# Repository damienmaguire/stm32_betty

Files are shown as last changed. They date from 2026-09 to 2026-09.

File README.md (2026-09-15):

# stm32_betty

Gen 2 Prius (NHW20) Battery ECU on a **ZombieVerter VCU V1.3**.

This software enables the use of 3 × BMW Gen 1 PHEV 16s modules (48s, 26 Ah) as the hybrid battery in a Gen 2 Toyota Prius car.

PHEV fuction via a Prius Plug-In OBC G9090-47040 in progress.
install1

Charger install in progress:
Charger_install

CAUTION : THIS FIRMWARE IS ALMOST ENTIRELY AI WRITTEN AND HAS NOT AS YET BEEN ROAD TESTED.

Provides various drive modes on the web interface.

## Buses

| Bus | Rate | Use |
|---|---|---|
| CAN1 | 500 k | Prius `0x03B` / `0x3C9` / `0x3CB` / `0x3CD` / `0x4D1` |
| CAN2 | 500 k | BMW CSC poll `0x080–0x085`, replies addrs 2/3/4 |
| GP_analog1 (PC2) | — | Prius Hall after 1k/1k on V1.3 |
| USART3 | 115200 | OpenInverter terminal + ESP web |

## Drive modes (ESP page, category Drive Mode)

| `mode` | What the HV ECU is told |
|---|---|
| 0 Hold | Default. Real 25–85 % mapped to a Prius 50–70 % report |
| 1 CD | Report `cdspoof` (~74 %) until `socreal` ≤ `cdfloor`, then Hold |
| 2 EV | Report `evspoof` (~60 %) and keep CCL ≥ 60 so the EV button is allowed |
| 3 Range | CDL = 0 — force the engine |
menu

## Build

```bash
sudo apt install gcc-arm-none-eabi
git clone --recurse-submodules https://github.com/damienmaguire/stm32_betty.git
cd stm32_betty
make
```

`make` runs `get-deps`: initialises the libopencm3 / libopeninv submodules (or clones them if you grabbed a zip) and builds `libopencm3` for STM32F1.

Flash like any Zombie. Linker origin is **0x08001000** (OpenInverter bootloader):

Or the ESP web updater / CubeProgrammer.

## Wiring (V1.3)

- Prius hybrid CAN → CAN1
- CSC loom (Yel/Brn + Yel/Red, 5 V + GND) → CAN2
- Hall yellow after 1k/1k → GP analog 1. Rest `ibpin` ≈ 1.21–1.25 V
- Board 12 V from IGCT (or parked 12 V). Sleep-override jumper fitted
- `CANEN` / `CANSBY` driven in firmware

## Status (2026-09-11)

Firmware v4. Pack in, IGCT Ready, no triangle.

GPL-3.0, same as OpenInverter / Zombie.

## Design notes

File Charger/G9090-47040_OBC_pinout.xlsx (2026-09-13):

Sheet: Notes
Betty — Toyota Prius Plug-In OBC G9090-47040 (ZVW35) pinout
Electric Vehicle Charger Assembly • connectors L120(A) / T10(B) / T11(C) • from OEM EWD snippet + ATI ZVW35 notes • 2026-09-13
What this unit is
Air-cooled Prius Plug-In onboard charger, part G9090-47040, 2012–2015 ZVW35. OEM rating is roughly 2 kW class on a 15 A EVSE.
How OEM drives it
Stock car has a Plug-in Charge Control ECU (PCC).Sends CHRQ + CHPW, reads CHST + VCHG.Zombie will fake those four wires.
HV path on Betty
DCHG is HV DC−, DCHB is HV DC+. Fuse DCHB, then land on the pack side of the Prius SMRs.
12 V
IGCT (A1, blue/L) with the VCU. Same rail that already boots the CSCs. CGND (A6 brown) is the charger signal ground — bond it to VCU ground.
EVSE / inlet
Right-hand block is the charge inlet: ACIH / ACIC (mains), GND, CPLT (J1772 control pilot), PISW (proximity / connector-present via the onboard resistor). CPG is pilot/PE ground.
Safety
Mains and HV on the same assembly. Isolate, fuse ACIH, fuse DCHG. No Prius frames on CAN2, no CSC frames on CAN1. This sheet is a wiring aid, not a live-work procedure.
Sheets: Pinout = every labelled net on the attached EWD. Diagram = the source drawing. Betty map = suggested landing on the Zombie / pack.

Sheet: Pinout
G9090-47040 • connections visible on the attached EWD
Connector family on the charger body: L120(A) T10(B) T11(C). Far-side IDs (E18, D27, At1, Ts1, T11) are as drawn. Colours are Toyota EWD codes.
Group | Signal | OBC pin | Far pin / ID | Colour | Class | Function | Betty / Zombie note
Control (PCC) | CHST | A2 | E18 CHST | G green | 12 V PWM out | Charge status from the OBC to the PCC ECU. Standby ≈ 25 ms B+ every 100 ms; ready ≈ 50 % duty; fault ≈ 78 % duty (overtemp / bad AC / internal). | Read on a Zombie GPIO or timer-in. Do not leave floating — PCC used it as the ‘charger is alive’ lamp.
Control (PCC) | CHPW | A3 | E19 CHPW | P pink | 12 V PWM in | Charge-power / current command from the PCC. 10 Hz PWM; on-time sets requested output. | Zombie must generate this. Start conservative (low duty).
Control (PCC) | CHRQ | A4 | E27 CHRQ | V purple | 12 V digital in | Charge request. High/low from the PCC: ‘please charge’. | Zombie GPIO out. Gate with umax / udc / EVSE present / Ready-not-in-Drive.
Control (PCC) | CGND | A6 | D27 CGND | BR brown | Signal GND | Charger control-signal ground. | Bond to VCU ground.
Control (PCC) | VCHG | A8 | D32 VCHG | W white | Analog out | Isolated analog of charger/pack voltage back to the PCC. OEM range quoted 1.72–6.0 V. | Useful cross-check vs CSC sumV.
Control (PCC) | VAC sense | A5 GVAC / A7 VAC1 | drawn as B and W pair | B black / W white | Analog / AC sense | GVAC and VAC1 sit on the same charger header as the PCC wires. Almost certainly AC-input voltage sense, not HV. | Leave unconnected until checked.
12 V power | IGCT | A1 | IGCT rail (blue) | L blue | 12 V in | Ignition / control power for the charger electronics. Same name as the Prius HV-ECU IGCT feed. | Tie to VCU IGCT. Board + CSCs + OBC cold-boot together. No permanent 12 V on the OBC until we know the no-IGCT draw.
HV DC out | DCHG | C2 | Ts1-1 | O-B orange/black, shielded | HV DC | HV DC− (negative). Shielded pair with DCHB. Lands on Ts1-1 in the drawing. | Fuse the positive (DCHB), then pack− side of the Prius SMRs. Confirmed: DCHG = DC−.
HV DC out | DCHB | C1 | Ts1-2 | O-W orange/white, shielded | HV DC | HV DC+ (positive). Shielded pair with DCHG. Lands on Ts1-2 in the drawing. | Fuse this leg, then pack+ side of the Prius SMRs. Confirmed: DCHB = DC+.
HV DC out | CHG | A12 | 4B-27 / 4A-42 | W-B white/black | 12 V / interlock (confirm) | Leaves the charger as W-B to a spliced junction (4B/4A). Not the orange HV pair. Likely charger +B, charge-relay coil, or an interlock — EWD snippet does not name the far ECU.
AC in | ACIH | B2 | T11-2 (inlet pin 1) | O-W orange/white, shielded | Mains Live | AC In Hot. Fused, CCID-protected live from the EVSE / inlet.
AC in | ACIC | B1 | T11-1 (inlet pin 2) | O-B orange/black, shielded | Mains Neutral | AC In Cold (neutral).
Inlet / J1772 | CPLT | inlet pin 4 → At1-1 | B23 CPLT | W white (then B at header) | Pilot | J1772 Control Pilot. EVSE PWM advertises available amps; vehicle pulls the pilot down to 6 V to say ‘ready’. | Zombie will handle
Inlet / J1772 | CPG | inlet / At1-3 | B10 CPG | W-B white/black | PE / pilot GND | Control-pilot / protective earth reference at the inlet header. | Chassis / PE.
Inlet / J1772 | PISW | inlet pin 5 → At1-2 | B12 PISW | B then R black/red | Proximity | Connector-present / proximity. Inlet pin 5 through the onboard PISW/CF resistor (green to earth) so the ECU sees a voltage, not a dead short. | Use as ‘plug is in’ before asserting CHRQ. <1 V typically means don’t charge; ~8 V means charge on the OEM PCC. Zombie will handle.
Inlet / J1772 | PISW resistor | inlet CF block | earth G | G green | Sense resistor | OEM proximity resistor at the inlet. Changes the voltage the PCC/OBC sees when the latch is closed. | Keep the OEM inlet if possible — the resistor is part of the PISW circuit.
Inlet / J1772 | GND (inlet) | inlet pin 3 | At1-3 / PE | L blue at pin, B on splice | PE | Inlet earth / PE pin. | Bond to vehicle chassis.
HV sense grounds | Ts1 shields | Ts1-4 B / Ts1-5 W | shield drains | B / W | Shield | Shield drains for the DCHG/DCHB pair, drawn to octagon splice points. | Single-end chassis bond.
AC shields | ACIC/ACIH shields | B1/B2 dashed | octagon splices | shield | Shield | Shields on the AC pair between charger B and inlet T11. | Single-end chassis bond.
Colour key: green = control/PWM/analog red tint = 12 V power purple tint = HV DC orange tint = mains AC grey = grounds/shields yellow = confirm on the unit
Sources: attached Toyota EWD snippet (L120/T10/T11); Automotive Tech Info ‘On The Juice’ ZVW35 PCC/OBC signal notes (CHST/CHPW/CHRQ/VCHG/CPLT/PISW/ACIH/ACIC). Pins not drawn on the snippet are omitted rather than guessed.

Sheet: Diagram
Source drawing — Electric Vehicle Charger Assembly L120(A) T10(B) T11(C)
Left block = charger. Right block = charge inlet (CPLT / GND / PISW / ACIH / ACIC). Bottom = HV DC pair to Ts1 and IGCT.
Attached file charger2.png. Labels used on the Pinout sheet are taken from this drawing only.

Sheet: Betty map
ZombieVerter Wiring
OBC signal | Goes to | When | Status
IGCT | VCU IGCT 12 V | Always with the board
CGND | VCU GND | Always
CHRQ | Zombie PWM1 | EVSE in + cells healthy + not in Drive
CHPW | Zombie PWM2, 10 Hz | While CHRQ is asserted
CHST | Zombie Brake Input | Always while IGCT is up
VCHG | Zombie analog2 in | Nice to have
DCHG / DCHB | DCHB (DC+) fused → pack+ side of SMRs. DCHG (DC−) → pack−. | Only after polarity check
ACIH / ACIC / PE | Charge inlet / EVSE | When an EVSE is plugged
CPLT | Control Pilot. Zombie Start input | When an EVSE is plugged
PISW/PP | Plug Present. Zombie Hvrequest input. | When an EVSE is plugged
CHG (W-B) | Charge port ground

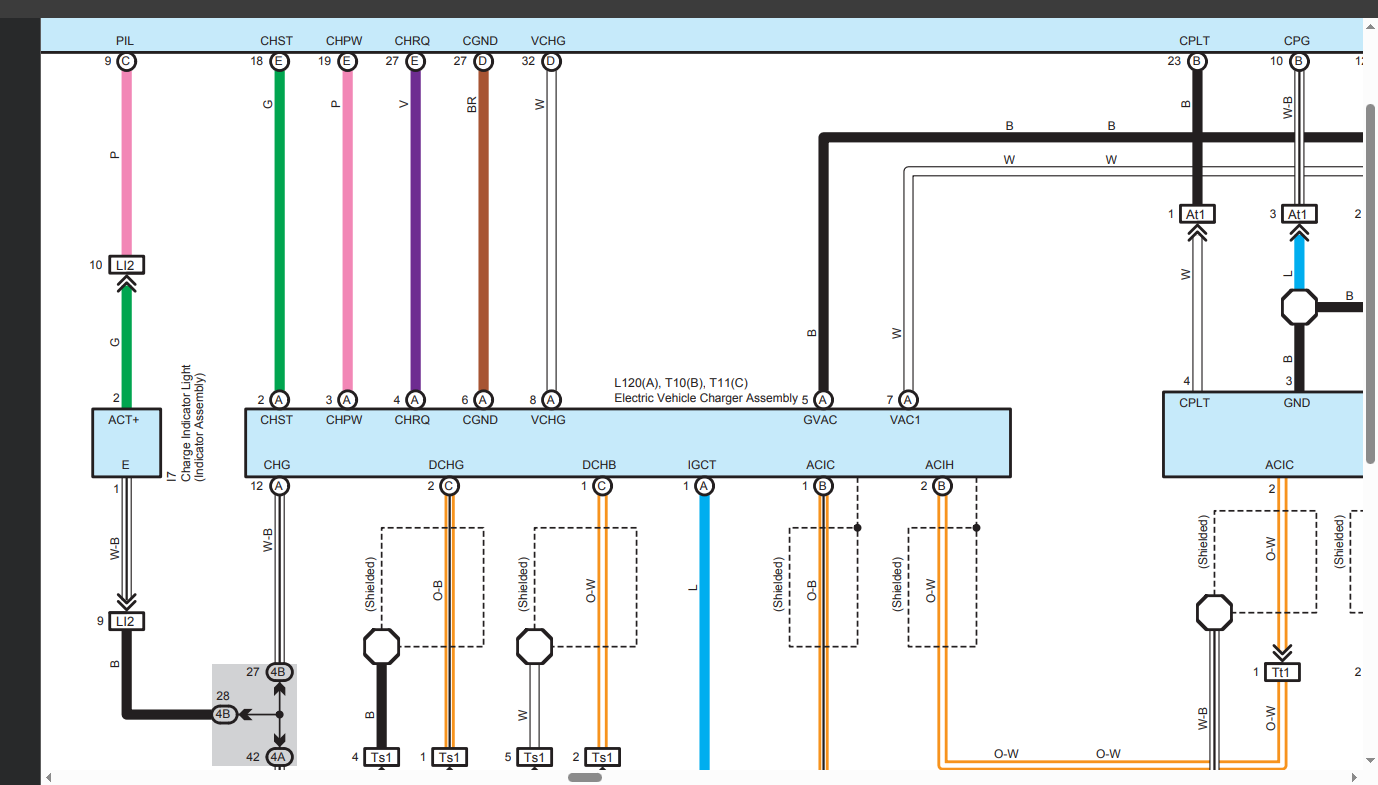
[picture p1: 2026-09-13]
Charger/charger1.png

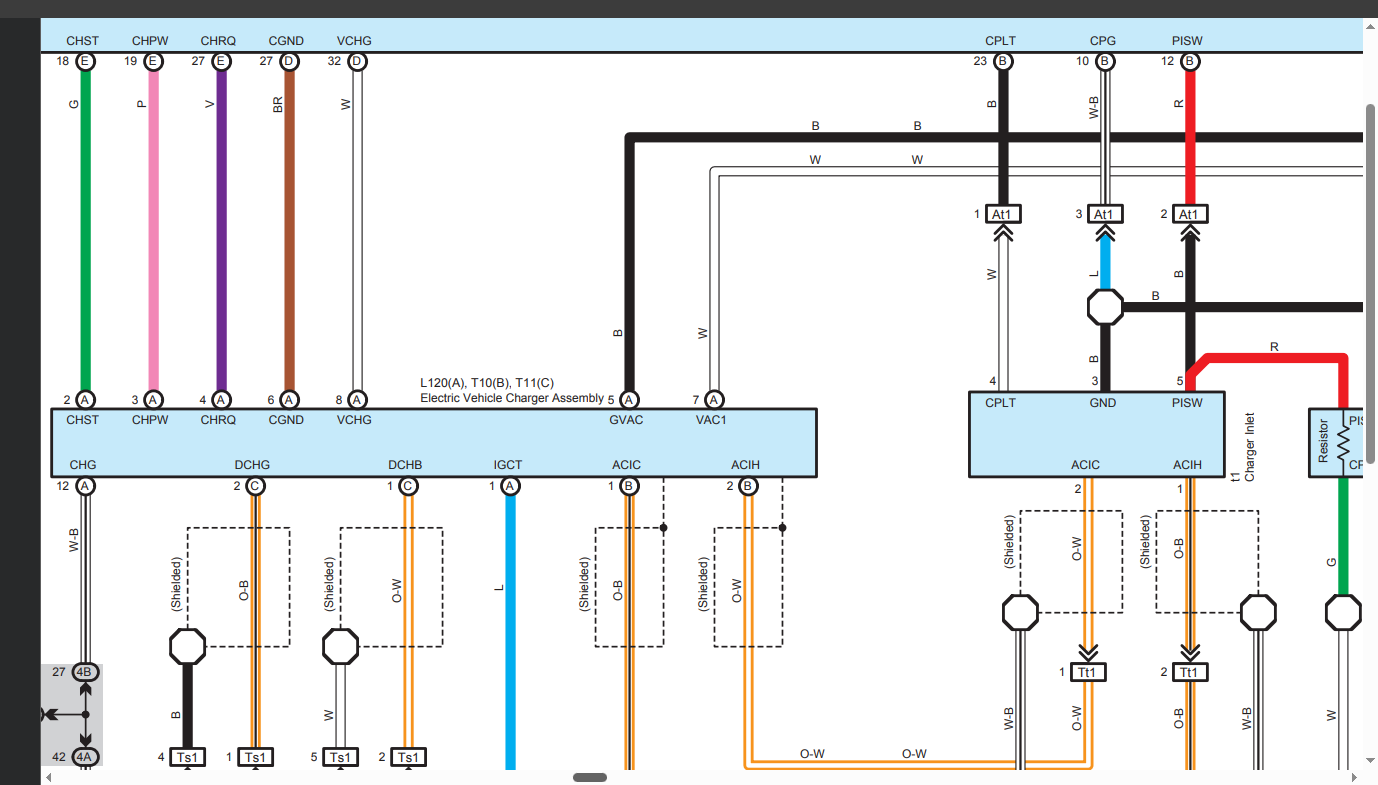
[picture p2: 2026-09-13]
Charger/charger2.png

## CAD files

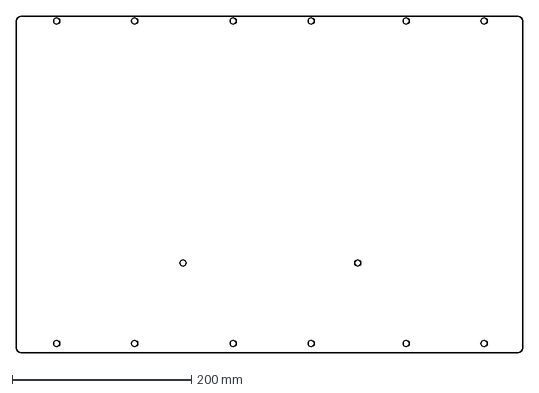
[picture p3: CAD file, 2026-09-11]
CAD/bmw_to_prius1-Body.dxf
565.0 x 375.0 mm

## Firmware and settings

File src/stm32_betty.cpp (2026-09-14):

/*
 * stm32_betty — Gen 2 Prius Battery ECU on ZombieVerter VCU V1.3
 *
 * CAN1 500 k: Prius 0x03B / 0x3C9 / 0x3CB / 0x3CD / 0x4D1
 * CAN2 500 k: 3 x BMW PHEV 16s CSC (addrs 2/3/4)
 * Analog GP_analog1: Prius IB sensor after 1k/1k on V1.3
 *
 * ESP8266 web UI on the VCU shows PARAM / VALUE list over USART3.
 *
 * v10: Charge mode — low SOC spoof so HV ECU engine-charges in Park
 */
#include "anain.h"
#include "bmw_crc.h"
#include "canhardware.h"
#include "digio.h"
#include "hwdefs.h"
#include "hwinit.h"
#include "param_save.h"
#include "params.h"
#include "stm32_can.h"
#include "stm32scheduler.h"
#include "terminal.h"
#include "terminalcommands.h"
#include <libopencm3/stm32/usart.h>
#include <math.h>
#include <string.h>
#include <libopencm3/stm32/can.h>
#include <libopencm3/stm32/usart.h>
#include <libopencm3/stm32/iwdg.h>
#include <libopencm3/stm32/gpio.h>
#include <math.h>
#include <string.h>
#include "canmap.h"

extern const TERM_CMD TermCmds[];

extern "C" void __cxa_pure_virtual()
{
    while (1);
}

#define CELLS_PER_MOD 16
#define NMOD 3
#define ADDR0 2
#define CELLS_PACK (CELLS_PER_MOD * NMOD)
#define PACKV_HOLD_FALLBACK 181.0f

enum DriveMode {
  MODE_HOLD = 0,
  MODE_CD = 1,
  MODE_EV = 2,
  MODE_RANGE = 3,
  MODE_CHARGE = 4
};

static Stm32Scheduler *scheduler;
static CanHardware *priusCan;
static CanHardware *cscCan;

struct CellMod {
  bool exists;
  float cell[CELLS_PER_MOD];
  float temp[4];
  uint32_t lastMs;
};
static CellMod mods[NMOD];

static float lastGoodV = 0;
static float packV = PACKV_HOLD_FALLBACK, packA = 0, minCell = 0, maxCell = 0;
static float tMin = 25, tMax = 25;
static uint8_t modulesSeen = 0;
static uint8_t cellsSeen = 0;
static uint16_t faultWord = 0;
static float socAh = 15.6f, socReal = 60, socOcv = 60;
static bool socSeeded = false;
static uint32_t tRest = 0, tBorn = 0, bootMs = 0, lastPriusRx = 0;
static uint8_t nextmes = 0, mescycle = 0;
static uint32_t uptimeSec = 0;

static volatile uint32_t millisCnt;
static uint32_t nowMs() { return millisCnt; }

static bool inBootGrace() {
  uint32_t g = (uint32_t)Param::GetInt(Param::bootgrace);
  return (nowMs() - bootMs) < g;
}

static uint8_t priusChecksum(uint16_t id, const uint8_t *data, uint8_t dlc) {
  uint16_t s = (id >> 8) + (id & 0xFF) + dlc;
  for (uint8_t i = 0; i < dlc - 1; i++)
    s += data[i];
  return (uint8_t)(s & 0xFF);
}

static void sendStd(CanHardware *bus, uint16_t id, const uint8_t *d, uint8_t len) {
  uint8_t buf[8] = {0};
  memcpy(buf, d, len);
  bus->Send(id, buf, len);
}

static int slotFromAddr(int addr) {
  if (addr < ADDR0 || addr > ADDR0 + NMOD - 1)
    return -1;
  return addr - ADDR0;
}

static float ocvSocFromCell(float v) {
  static const float vv[] = {3.20f, 3.40f, 3.50f, 3.55f, 3.62f, 3.70f,
                             3.78f, 3.85f, 3.92f, 4.00f, 4.10f};
  static const float ss[] = {0, 10, 20, 30, 40, 50, 60, 70, 80, 90, 100};
  const int n = 11;
  if (v <= vv[0])
    return ss[0];
  if (v >= vv[n - 1])
    return ss[n - 1];
  for (int i = 1; i < n; i++) {
    if (v <= vv[i]) {
      float f = (v - vv[i - 1]) / (vv[i] - vv[i - 1]);
      return ss[i - 1] + f * (ss[i] - ss[i - 1]);
    }
  }
  return 50;
}

static void applyOcv(float pct) {
  if (pct < 1)
    pct = 1;
  if (pct > 99)
    pct = 99;
  socOcv = pct;
  socReal = pct;
  socAh = Param::GetFloat(Param::packah) * (pct / 100.0f);
  socSeeded = true;
}

static float readCurrentA() {
  uint16_t raw = AnaIn::GP_analog1.Get();
  float vpin = raw * (3.3f / 4095.0f);
  Param::SetInt(Param::ibadc, raw);
  Param::SetFloat(Param::ibpin, vpin);
  float zero = Param::GetFloat(Param::ibzero);
  float div = Param::GetFloat(Param::ibdiv);
  float gain = Param::GetFloat(Param::ibgain);
  return ((vpin - zero) / div) * gain;
}

static void updatePackFromCsc() {
  float sumV = 0, cmin = 5, cmax = 0, tmn = 200, tmx = -100;
  uint8_t seen = 0;
  uint8_t cells = 0;
  uint32_t now = nowMs();
  for (int m = 0; m < NMOD; m++) {
    if (!mods[m].exists)
      continue;
    if (now - mods[m].lastMs > 5000) {
      mods[m].exists = false;
      continue;
    }
    seen++;
    for (int c = 0; c < CELLS_PER_MOD; c++) {
      float v = mods[m].cell[c];
      if (v < 0.5f || v > 5.0f)
        continue;
      cells++;
      sumV += v;
      if (v < cmin)
        cmin = v;
      if (v > cmax)
        cmax = v;
    }
    for (int t = 0; t < 4; t++) {
      float tp = mods[m].temp[t];
      if (tp <= -39)
        continue;
      if (tp >= 54.5f && tp <= 55.5f) /* unused CSC thermistor byte */
        continue;
      if (tp < tmn)
        tmn = tp;
      if (tp > tmx)
        tmx = tp;
    }
  }
  modulesSeen = seen;
  cellsSeen = cells;
  minCell = (cmin < 5) ? cmin : 0;
  maxCell = cmax;
  if (cells >= CELLS_PACK && sumV > 20.0f) {
    packV = sumV;
    lastGoodV = sumV;
    Param::SetFloat(Param::packvhold, sumV);
  } else if (lastGoodV > 20.0f) {
    packV = lastGoodV;
  } else {
    packV = Param::GetFloat(Param::packvhold);
  }
  if (tmn < 200)
    tMin = tmn;
  if (tmx > -100)
    tMax = tmx;
}

static void updateSoc(float dt) {
  if (dt <= 0 || dt > 1.0f)
    dt = 0.01f;
  socAh -= packA * dt / 3600.0f;
  float cap = Param::GetFloat(Param::packah);
  if (socAh < 0.1f)
    socAh = 0.1f;
  if (socAh > cap)
    socAh = cap;
  socReal = 100.0f * socAh / cap;
  if (minCell > 0.5f)
    socOcv = ocvSocFromCell(minCell);

  uint32_t now = nowMs();
  bool resting = (packA > -1.5f && packA < 1.5f && minCell > 0.5f);
  if (!resting)
    tRest = now;
  if (!socSeeded && minCell > 0.5f) {
    if ((resting && (now - tRest) >= 2000) || (now - tBorn) >= 5000)
      applyOcv(socOcv);
  } else if (socSeeded && resting && (now - tRest) >= 8000) {
    applyOcv(socOcv);
    tRest = now;
  }
}

static uint8_t holdSpoof() {
  float rmin = Param::GetFloat(Param::socrealmin);
  float rmax = Param::GetFloat(Param::socrealmax);
  float smin = Param::GetFloat(Param::spoofmin);
  float smax = Param::GetFloat(Param::spoofmax);
  float real = socReal;
  if (real < rmin)
    real = rmin;
  if (real > rmax)
    real = rmax;
  float spoof = smin + ((real - rmin) / (rmax - rmin)) * (smax - smin);
  if (spoof < smin)
    spoof = smin;
  if (spoof > smax)
    spoof = smax;
  return (uint8_t)(spoof + 0.5f);
}

static uint8_t socToReport() {
  int mode = Param::GetInt(Param::mode);
  if (mode == MODE_CD) {
    if (socReal > Param::GetFloat(Param::cdfloor))
      return (uint8_t)(Param::GetFloat(Param::cdspoof) + 0.5f);
    return holdSpoof();
  }
  if (mode == MODE_EV)
    return (uint8_t)(Param::GetFloat(Param::evspoof) + 0.5f);
  if (mode == MODE_CHARGE) {
    if (socReal >= Param::GetFloat(Param::chargeceil))
      return holdSpoof();
    return (uint8_t)(Param::GetFloat(Param::chargespoof) + 0.5f);
  }
  /* HOLD and RANGE use the 50–70 map */
  return holdSpoof();
}

static void limitsFromHealth(uint8_t &cdl, uint8_t &ccl) {
  cdl = (uint8_t)Param::GetInt(Param::cdl);
  ccl = (uint8_t)Param::GetInt(Param::ccl);
  faultWord = 0;

  bool grace = inBootGrace();
  if (modulesSeen < NMOD && !grace) {
    cdl = 20;
    ccl = 0;
    faultWord = 0x3030;
  }
  if (minCell > 0.5f && minCell < 3.30f)
    cdl = 20;
  if (maxCell > 4.00f)
    ccl = 10;
  if (minCell > 0.5f && minCell < 3.20f) {
    cdl = 0;
    faultWord = 0x0A7F;
  }
  if (maxCell > 4.05f) {
    ccl = 0;
    faultWord = 0x0A7F;
  }

  /* Modes only apply while the pack is healthy. */
  if (faultWord == 0) {
    int mode = Param::GetInt(Param::mode);
    if (mode == MODE_EV && ccl < 60)
      ccl = 60;
    if (mode == MODE_RANGE)
      cdl = 0;
    if (mode == MODE_CHARGE) {
      cdl = 0;
      if (socReal >= Param::GetFloat(Param::chargeceil))
        ccl = 0;
    }
  }
}

static void tx03B() {
  int32_t raw = (int32_t)(packA * 10.0f);
  if (raw > 2047)
    raw = 2047;
  if (raw < -2048)
    raw = -2048;
  uint16_t u = (uint16_t)(raw & 0x0FFF);
  uint16_t v = (uint16_t)packV;
  if (v > 510)
    v = 510;
  uint8_t d[5];
  d[0] = (u >> 8) & 0x0F;
  d[1] = u & 0xFF;
  d[2] = v >> 8;
  d[3] = v & 0xFF;
  d[4] = priusChecksum(0x03B, d, 5);
  sendStd(priusCan, 0x03B, d, 5);
}

static void tx3CB() {
  uint8_t cdl, ccl;
  limitsFromHealth(cdl, ccl);
  uint8_t soc = socToReport();
  uint8_t d[7];
  d[0] = cdl;
  d[1] = ccl;
  d[2] = 0;
  d[3] = (uint8_t)(soc * 2);
  d[4] = (uint8_t)((int)tMin & 0xFF);
  d[5] = (uint8_t)((int)tMax & 0xFF);
  d[6] = priusChecksum(0x3CB, d, 7);
  sendStd(priusCan, 0x3CB, d, 7);
}

static void tx3CD() {
  uint16_t v = (uint16_t)packV;
  if (v > 510)
    v = 510;
  uint8_t d[5];
  d[0] = faultWord >> 8;
  d[1] = faultWord & 0xFF;
  d[2] = v >> 8;
  d[3] = v & 0xFF;
  d[4] = priusChecksum(0x3CD, d, 5);
  sendStd(priusCan, 0x3CD, d, 5);
}

static void tx3C9() {
  uint16_t blockCv = (uint16_t)(packV / 14.0f * 100.0f + 0.5f);
  if (blockCv < 800)
    blockCv = 800;
  if (blockCv > 1800)
    blockCv = 1800;
  uint8_t d[8];
  d[0] = 0x03;
  d[1] = 0xFF;
  d[2] = 0x21;
  d[3] = (uint8_t)(blockCv >> 8);
  d[4] = (uint8_t)(blockCv & 0xFF);
  d[5] = d[3];
  d[6] = d[4];
  d[7] = priusChecksum(0x3C9, d, 8);
  sendStd(priusCan, 0x3C9, d, 8);
}

static void tx4D1() {
  uint8_t d[8] = {0x11, 0x00, 0x01, 0x02, 0x00, 0x00, 0x00, 0x00};
  sendStd(priusCan, 0x4D1, d, 8);
}

static void pollBmw() {
  if (!cscCan)
    return;
  if (nextmes >= 6) {
    nextmes = 0;
    mescycle++;
    if (mescycle > 0x0F)
      mescycle = 0;
  }
  uint16_t id = 0x080 + nextmes;
  uint8_t d[8] = {0xC7, 0x10, 0x00, 0x00, 0x40, 0x01, 0x00, 0x00};
  d[6] = (uint8_t)(mescycle << 4);
  d[7] = BmwCrc::calc(id, d, 8, nextmes);
  sendStd(cscCan, id, d, 8);
  nextmes++;
}

static void handleBmw(uint32_t canId, uint32_t data[2], uint8_t /*dlc*/) {
  uint8_t b[8];
  memcpy(b, data, 8);
  int addr = (int)(canId & 0xF);
  int slot = slotFromAddr(addr);
  if (slot < 0)
    return;
  mods[slot].exists = true;
  mods[slot].lastMs = nowMs();
  int mid = (int)((canId >> 4) & 0xF);
  if (mid >= 2 && mid <= 7) {
    int base = (mid - 2) * 3;
    for (int i = 0; i < 3; i++) {
      int idx = base + i;
      if (idx >= CELLS_PER_MOD)
        break;
      uint16_t mv = (uint16_t)b[i * 2] | ((uint16_t)b[i * 2 + 1] << 8);
      if (mv > 500 && mv < 5000)
        mods[slot].cell[idx] = mv * 0.001f;
    }
  }
  /* 0x182–184 only. mid==0 also matches 0x102 heartbeat and 0x202 status. */
  if (canId >= 0x182 && canId <= 0x184) {
    for (int i = 0; i < 4; i++)
      mods[slot].temp[i] = (float)b[i] - 40.0f;
  }
}

static bool CscRx(uint32_t canId, uint32_t *data, uint8_t dlc) {
  handleBmw(canId, data, dlc);
  return false;
}
static void CscClear() {}

static bool PriusRx(uint32_t /*canId*/, uint32_t * /*data*/, uint8_t /*dlc*/) {
  lastPriusRx = nowMs();
  return false;
}
static void PriusClear() {}

static bool carAwake() {
  if (lastPriusRx == 0)
    return false;
  return (nowMs() - lastPriusRx) < 1000;
}

static void publish() {
  Param::SetFloat(Param::udc, packV);
  Param::SetFloat(Param::idc, packA);
  Param::SetInt(Param::soc, socToReport());
  Param::SetFloat(Param::socreal, socReal);
  Param::SetFloat(Param::sococv, socOcv);
  Param::SetFloat(Param::socah, socAh);
  Param::SetFloat(Param::umin, minCell);
  Param::SetFloat(Param::umax, maxCell);
  float dv = 0;
  if (minCell > 0.5f && maxCell > minCell)
    dv = maxCell - minCell;
  Param::SetFloat(Param::deltav, dv);
  Param::SetFloat(Param::tmpmin, tMin);
  Param::SetFloat(Param::tmpmax, tMax);
  Param::SetInt(Param::mods, modulesSeen);
  Param::SetInt(Param::fault, faultWord);
  Param::SetInt(Param::cells, cellsSeen);
  Param::SetInt(Param::version, VER);
  Param::SetFloat(Param::power, packV * packA / 1000.0f);
  Param::SetInt(Param::uptime, (int)uptimeSec);
  if (carAwake())
    Param::SetInt(Param::opmode, Param::GetInt(Param::mode) + 1);
  else
    Param::SetInt(Param::opmode, 0);
  float uaux = AnaIn::uaux.Get() * (3.3f / 4095.0f) * 9.2f; // typical zombie scale-ish
  Param::SetFloat(Param::uaux, uaux);
}

static void Ms1Task() {
  millisCnt++;
  static uint8_t div = 0;
  if (++div < 8)
    return;
  div = 0;
  tx03B();
}

static void Ms10Task() {
  packA = readCurrentA();
  updatePackFromCsc();
  updateSoc(0.010f);
  pollBmw();
}

static void Ms100Task() {
  iwdg_reset();
  tx3CB();
  tx3CD();
  tx3C9();
  publish();
  if (scheduler)
    Param::SetFloat(Param::cpuload, scheduler->GetCpuLoad() / 10.0f);
  DigIo::led_out.Toggle();
}

static void Ms1000Task() {
  tx4D1();
  uptimeSec++;
}

extern "C" void tim4_isr(void) { scheduler->Run(); }

void Param::Change(Param::PARAM_NUM /*paramNum*/) {}

static void SetCanFilters() {
  /* CAN1 first. RegisterUserMessage on CAN1 calls ConfigureFilters which
   * does CAN_FA1R(CAN1)=0 and wipes the shared F107 filter banks. CSC last. */
  priusCan->RegisterUserMessage(0x038);
  priusCan->RegisterUserMessage(0x348);
  priusCan->RegisterUserMessage(0x529);

  cscCan->RegisterUserMessage(0x122);
  cscCan->RegisterUserMessage(0x132);
  cscCan->RegisterUserMessage(0x142);
  cscCan->RegisterUserMessage(0x152);
  cscCan->RegisterUserMessage(0x162);
  cscCan->RegisterUserMessage(0x172);
  cscCan->RegisterUserMessage(0x123);
  cscCan->RegisterUserMessage(0x133);
  cscCan->RegisterUserMessage(0x143);
  cscCan->RegisterUserMessage(0x153);
  cscCan->RegisterUserMessage(0x163);
  cscCan->RegisterUserMessage(0x173);
  cscCan->RegisterUserMessage(0x124);
  cscCan->RegisterUserMessage(0x134);
  cscCan->RegisterUserMessage(0x144);
  cscCan->RegisterUserMessage(0x154);
  cscCan->RegisterUserMessage(0x164);
  cscCan->RegisterUserMessage(0x174);
  cscCan->RegisterUserMessage(0x182);
  cscCan->RegisterUserMessage(0x183);
  cscCan->RegisterUserMessage(0x184);
  cscCan->RegisterUserMessage(0x202);
  cscCan->RegisterUserMessage(0x203);
  cscCan->RegisterUserMessage(0x204);
}

int main(void) {
  iwdg_reset();
  clock_setup();
  gpio_primary_remap(AFIO_MAPR_SWJ_CFG_JTAG_OFF_SW_ON,
                   AFIO_MAPR_CAN2_REMAP);
  rtc_setup();
  nvic_setup();
  DIG_IO_CONFIGURE(DIG_IO_LIST);
  ANA_IN_CONFIGURE(ANA_IN_LIST);

  for (int i = 0; i < 16; i++) {
    DigIo::led_out.Toggle();
    for (volatile int d = 0; d < 300000; d++)
      ;
    iwdg_reset();
  }

  Stm32Scheduler s(TIM4);
  scheduler = &s;

  parm_load();
  iwdg_reset();
  AnaIn::Start();

  DigIo::CANEN.Set();
  DigIo::CANSBY.Set();
  DigIo::inv_out.Clear();

  Terminal t(USART3, TermCmds, false, true, !Param::GetBool(Param::UseRS232));

  Stm32Can can0(CAN1, CanHardware::Baud500);
  Stm32Can can1(CAN2, CanHardware::Baud500, true);
  priusCan = &can0;
  cscCan = &can1;

  CanMap cm(&can0);
  TerminalCommands::SetCanMap(&cm);

  FunctionPointerCallback cbCsc(CscRx, CscClear);
  can1.AddCallback(&cbCsc);
  FunctionPointerCallback cbPrius(PriusRx, PriusClear);
  can0.AddCallback(&cbPrius);
  SetCanFilters();

  packV = Param::GetFloat(Param::packvhold);
  packA = 0;
  faultWord = 0;
  bootMs = nowMs();
  tBorn = nowMs();

  s.AddTask(Ms1Task, 1);
  s.AddTask(Ms10Task, 10);
  s.AddTask(Ms100Task, 100);
  s.AddTask(Ms1000Task, 1000);

  while (1) {
    //iwdg_reset();
    t.Run();
  }
}

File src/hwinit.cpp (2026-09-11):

/*
 * Clock / NVIC / USART bring-up for ZombieVerter V1.3 (STM32F107).
 * Trimmed from stm32-vcu hwinit — no GS450H / SPI3 / PWM gauges.
 */
#include "hwinit.h"
#include "hwdefs.h"
#include <libopencm3/cm3/nvic.h>
#include <libopencm3/cm3/scb.h>
#include <libopencm3/stm32/gpio.h>
#include <libopencm3/stm32/rcc.h>
#include <libopencm3/stm32/usart.h>
#include <libopencm3/stm32/adc.h>
#include <libopencm3/stm32/dma.h>
#include <libopencm3/stm32/timer.h>

void clock_setup(void) {
  rcc_clock_setup_pll(&rcc_hse_configs[RCC_CLOCK_HSE8_72MHZ]);
  rcc_set_adcpre(RCC_CFGR_ADCPRE_PCLK2_DIV6);
  SCB_AIRCR = SCB_AIRCR_VECTKEY | SCB_AIRCR_PRIGROUP_GROUP16_NOSUB;

  rcc_periph_clock_enable(RCC_GPIOA);
  rcc_periph_clock_enable(RCC_GPIOB);
  rcc_periph_clock_enable(RCC_GPIOC);
  rcc_periph_clock_enable(RCC_GPIOD);
  rcc_periph_clock_enable(RCC_GPIOE);
  rcc_periph_clock_enable(RCC_USART3);
  rcc_periph_clock_enable(RCC_TIM4);
  rcc_periph_clock_enable(RCC_DMA1);
  rcc_periph_clock_enable(RCC_ADC1);
  rcc_periph_clock_enable(RCC_CRC);
  rcc_periph_clock_enable(RCC_AFIO);
  rcc_periph_clock_enable(RCC_CAN1);
  rcc_periph_clock_enable(RCC_CAN2);
}

void usart_setup(void) {}
void usart1_setup(void) {}
void usart2_setup(void) {}
void tim_setup(void) {}
void tim2_setup(void) {}
void tim3_setup(void) {}
void spi2_setup(void) {}
void spi3_setup(void) {}

void nvic_setup(void) {
  nvic_enable_irq(NVIC_TIM4_IRQ);
  nvic_set_priority(NVIC_TIM4_IRQ, 0);

  nvic_enable_irq(NVIC_USB_LP_CAN_RX0_IRQ);
  nvic_set_priority(NVIC_USB_LP_CAN_RX0_IRQ, 0xe << 4);
  nvic_enable_irq(NVIC_USB_HP_CAN_TX_IRQ);
  nvic_set_priority(NVIC_USB_HP_CAN_TX_IRQ, 0xe << 4);

  nvic_enable_irq(NVIC_CAN2_RX0_IRQ);
  nvic_set_priority(NVIC_CAN2_RX0_IRQ, 0xe << 4);
  nvic_enable_irq(NVIC_CAN2_TX_IRQ);
  nvic_set_priority(NVIC_CAN2_TX_IRQ, 0xe << 4);
}

void rtc_setup(void) {}

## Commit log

2026-09-11 v4: Prius Battery ECU spoof, BMW CSC, drive modes, packvhold
2026-09-11 Add board headers, CRC, hwinit, terminal, Code::Blocks project
2026-09-11 Add stm32_betty.cpp v4 (boot hold, modes, packvhold)
2026-09-11 Update Readme and add CAD
    [bmw_to_prius1-Body.dxf]
2026-09-12 Updates
    -Add engine charging mode
    -Add kW display
    -Add cell deltaV display
2026-09-13 Add AC Charger Info
    [G9090-47040_OBC_pinout.xlsx]
2026-09-14 Fixes
    -Fix race condition where we never sent an updated pack voltage after boot.
    -Fix max temps from CSCs.
    [stm32_betty.cpp]
